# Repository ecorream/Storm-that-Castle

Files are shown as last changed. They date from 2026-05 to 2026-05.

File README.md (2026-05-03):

# Storm that Castle — Autonomous Multi-HILL Capture Robot

This repository documents the design, electronics, control logic, and competition outcome of **Team 6's autonomous robot** for the ME 588 STORM competition: **Storm that Castle: Fight to be King of the HILL**.

The robot was designed to autonomously navigate the playing field, detect HILL status using infrared frequency sensing, position itself using ultrasonic distance feedback, and deploy foam UNITs using a servo-based delivery system. The central strategy was to capture multiple HILLs at the end of the match by delivering several UNITs nearly simultaneously.

## Competition Result

The project was successful. Although the robot experienced some distance-sensing challenges during development and competition runs, the final system reached the final round of the competition. The robot tied in the final match and finished **second place only by tiebreaker**.

This result showed that the team's design approach, competition strategy, mechanical concept, electronics integration, and control implementation were sufficient to compete at a high level and validate the overall system architecture.

<p align="center">
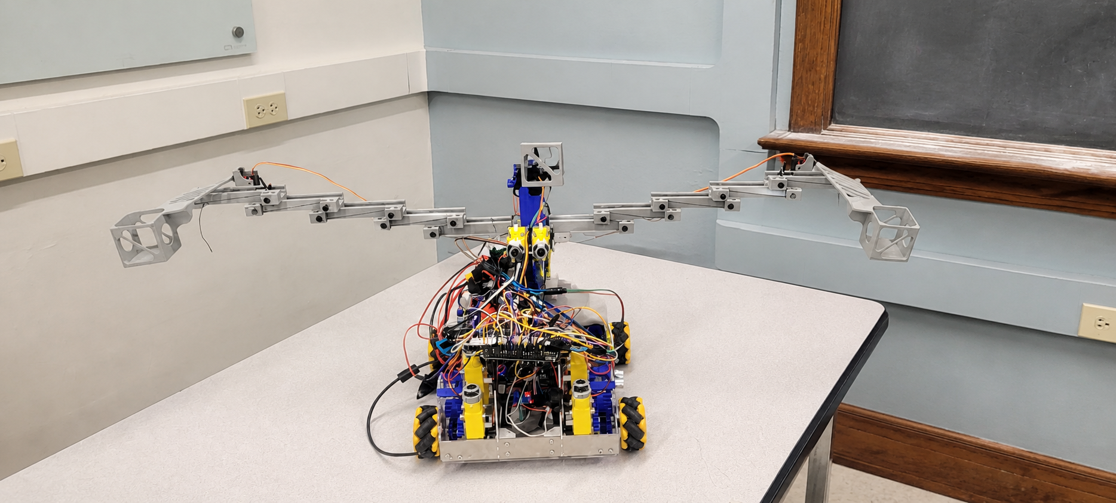
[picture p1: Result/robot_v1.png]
robot version 1
   
</p>

<p align="center">
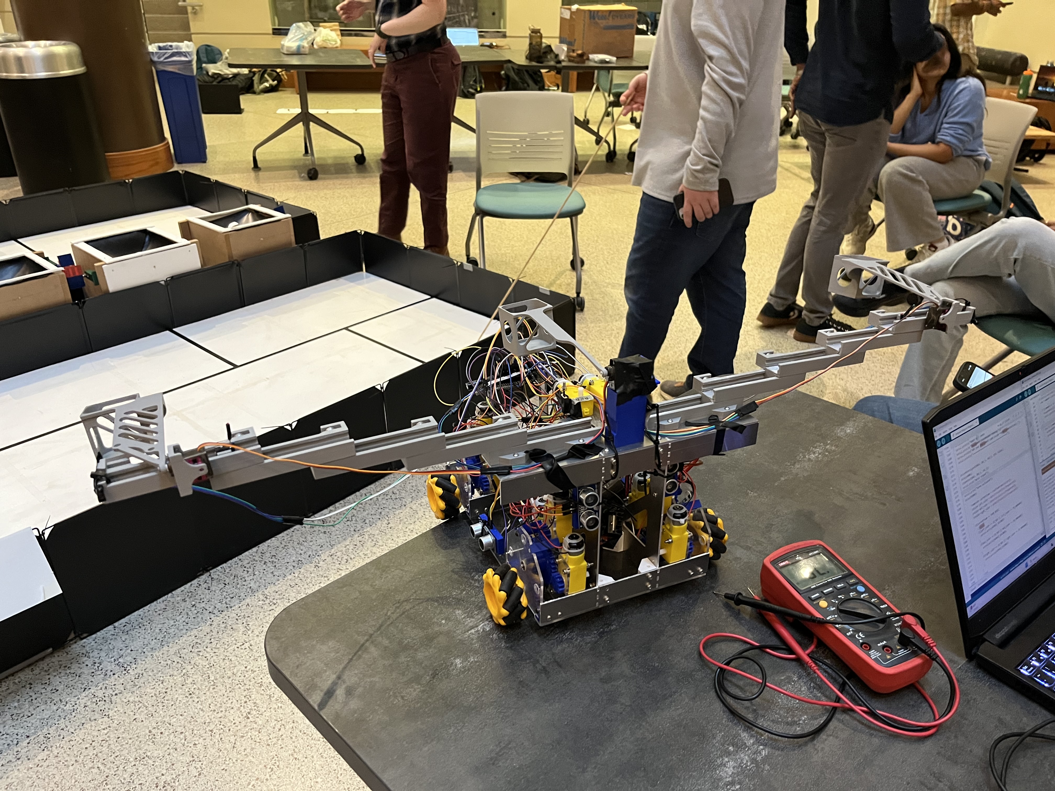
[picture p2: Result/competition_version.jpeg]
competition version robot
  
</p>

[Watch the final second round video](Result/final%20second%20round.mp4)

## Project Strategy

The main strategy was based on the fact that HILL control at the end of the match determines the result. Instead of continuously fighting for every HILL during the full match, the robot was designed to:

1. Navigate to the scoring position.
2. Align with multiple HILLs.
3. Deploy an extension/scoring system.
4. Release UNITs near the end of the match.
5. Capture multiple HILLs in a single final action.

This approach reduced the need for continuous scoring and focused on a decisive last-second capture.

## System Overview

The robot integrates the following major subsystems:

- **Mecanum-wheel drivetrain** for forward, backward, lateral, and alignment motion.
- **Ultrasonic sensing system** for distance-based navigation and positioning.
- **Infrared frequency detection system** for identifying HILL/team status.
- **AS5600 wheel encoders** connected through a TCA9548A I2C multiplexer.
- **Servo-controlled deployment system** for releasing UNITs.
- **APA102 LED display strip** for team selection and system status feedback.
- **Arduino Mega 2560** as the main controller.
- **L298N motor drivers** for drivetrain and deployment motor control.

## Repository Structure

```text
.
├── README.md
├── Competition_Arduino_code/
│   └── Competition_code.ino
├── Images/
│   ├── IR sensor.png
│   ├── arduino conections.png
│   ├── display.png
│   ├── encoders.png
│   ├── l298.png
│   ├── servos.png
│   ├── team selector.png
│   └── ultrasonic.png
├── KiCad files/
│   ├── lab7-backups/
│   ├── LEDS.kicad_sch
│   ├── distance.kicad_sch
│   ├── fp-info-cache
│   ├── lab7.kicad_pcb
│   ├── lab7.kicad_prl
│   ├── lab7.kicad_pro
│   ├── lab7.kicad_sch
│   ├── motors.kicad_sch
│   ├── power.kicad_sch
│   ├── servos.kicad_sch
│   └── untitled.kicad_sch
└── Result/
    ├── competition version.jpeg
    ├── drivetrain.png
    ├── final second round.mp4
    ├── robot.png
    └── robot_v1.jpeg
```

> The folder names above are recommended for organizing the GitHub repository. The images referenced in this README assume that all schematic images are stored inside the `Images/` folder.

## Electrical Architecture

The complete electrical system connects the Arduino Mega to the sensors, motor drivers, servos, LED strip, and team selector switch.

<p align="center">
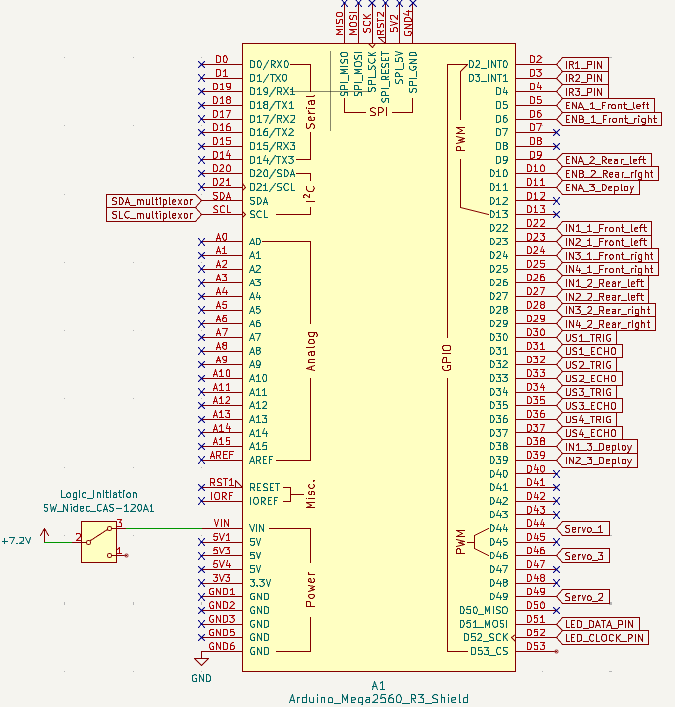
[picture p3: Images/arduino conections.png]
   
</p>

### Main Controller

The main controller is an **Arduino Mega 2560**, selected because the robot required a high number of digital I/O pins for ultrasonic sensors, IR sensors, motor drivers, servos, LEDs, and the I2C multiplexer.

## Team Selector

The team selector is implemented with a switch connected to the Arduino using an internal pull-up configuration. One side of the selector is connected to GND, and the signal pin is read by the controller to determine the active team color.

<p align="center">
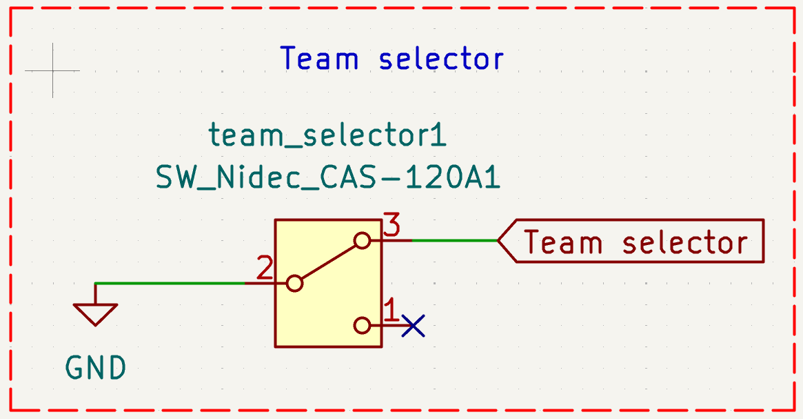
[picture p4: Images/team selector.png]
   
</p>

| Function | Arduino Pin | Notes |
|---|---:|---|
| Team selector signal | D40 | Uses `INPUT_PULLUP` |
| Switch common | GND | LOW state when connected to ground |

## Ultrasonic Sensor System

The robot uses four HC-SR04 ultrasonic sensors to estimate distances and support autonomous navigation. These sensors were used to approach HILL structures, maintain distance, and determine when the robot reached a deployment position.

<p align="center">
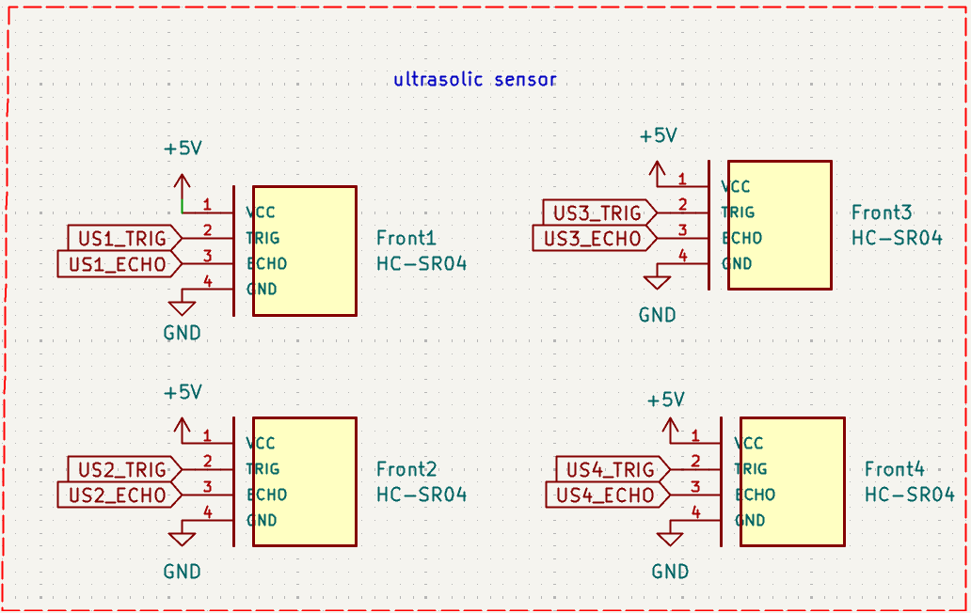
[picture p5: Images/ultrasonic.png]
   
</p>

| Sensor | Trigger Pin | Echo Pin | Purpose |
|---|---:|---:|---|
| US1 | D30 | D31 | Distance sensing |
| US2 | D32 | D33 | Distance sensing |
| US3 | D34 | D35 | Distance sensing |
| US4 | D36 | D37 | Distance sensing |

### Ultrasonic Calibration Notes

Some distance-sensing issues were observed during testing. The main improvements used during development were:

- Averaging multiple readings to reduce noise.
- Defining minimum and maximum valid distance thresholds.
- Using calibration offsets when two sensors were not mounted at exactly the same physical depth.
- Slowing the robot near the target to reduce overshoot.
- Testing distances repeatedly before competition runs.

Even with these challenges, the final robot was able to complete the strategy well enough to reach the final match.

## Infrared Frequency Sensor System

The IR system uses QSD123 NPN phototransistors with pull-up resistors. The Arduino reads the signal frequency and classifies the detected HILL/team state.

<p align="center">
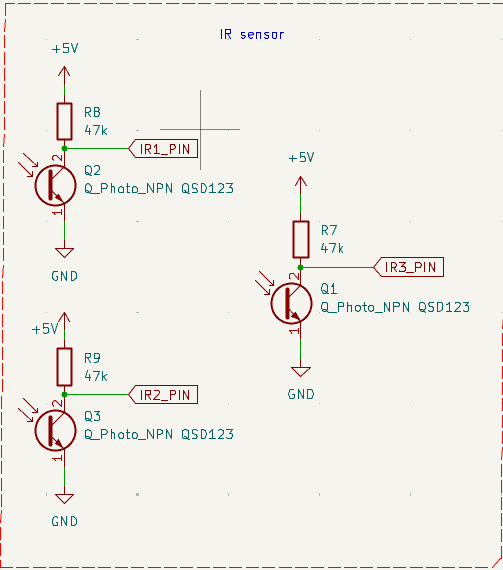
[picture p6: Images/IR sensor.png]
   
</p>

| IR Sensor | Arduino Pin | Function |
|---|---:|---|
| IR1 | D2 | Left reference / scoring position |
| IR2 | D3 | Center reference / scoring position |
| IR3 | D4 | Right reference / scoring position |

### Frequency Classification

The control software classifies the detected frequency into a team state. The working reference frequencies were:

| Team State | Approximate Frequency |
|---|---:|
| Blue | 780 Hz |
| Red | 1560 Hz |
| Unknown | Outside expected frequency range |

The IR readings were also displayed through the APA102 LED strip so the team could visually confirm what the robot was detecting during operation.

## Wheel Encoder System

Each wheel uses an AS5600 magnetic encoder. Because all AS5600 devices share the same I2C address, a **TCA9548A I2C multiplexer** is used to isolate each encoder on a separate bus channel.

<p align="center">
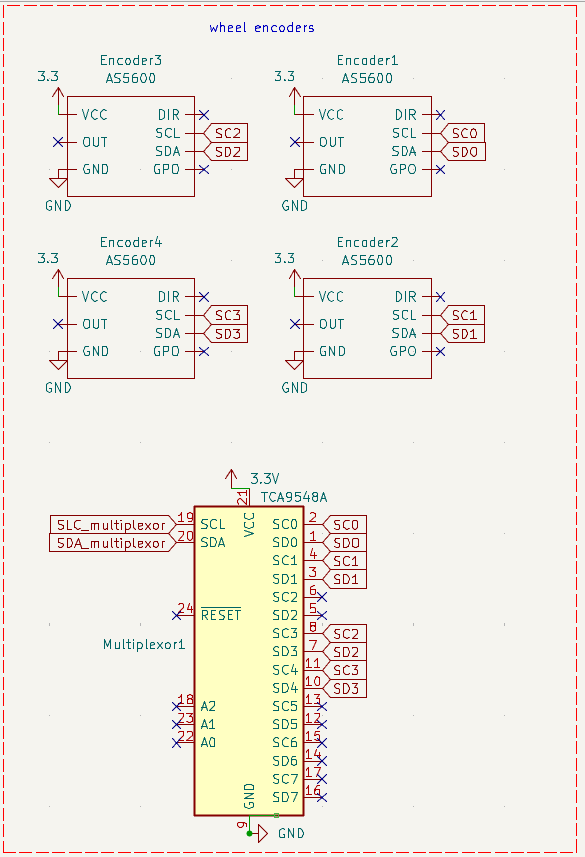
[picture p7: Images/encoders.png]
   
</p>

| Encoder | MUX Channel | Wheel Location |
|---|---:|---|
| Encoder 1 | Channel 0 | Front / drivetrain feedback |
| Encoder 2 | Channel 1 | Rear / drivetrain feedback |
| Encoder 3 | Channel 3 | Front / drivetrain feedback |
| Encoder 4 | Channel 4 | Rear / drivetrain feedback |

| I2C Signal | Arduino Mega Pin |
|---|---:|
| SDA | D20 |
| SCL | D21 |

The encoders were used mainly for wheel feedback, debugging, motor direction verification, and improving motion consistency.

## LED Display System

The robot uses an APA102 LED strip to provide visual feedback for team selection, navigation state, point detection, and IR frequency classification.

<p align="center">
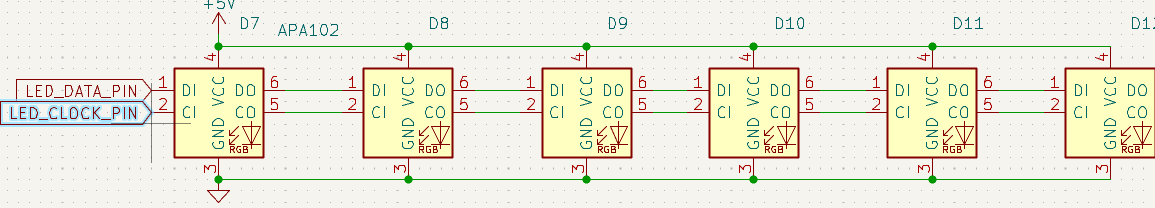
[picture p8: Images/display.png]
   
</p>

| LED Signal | Arduino Pin |
|---|---:|
| LED data | D51 |
| LED clock | D52 |
| VCC | +5V |
| GND | GND |

### LED Status Concept

| LED Position | Status Role |
|---|---|
| LED 1 | Selected team color |
| LED 2 | General system status |
| LED 3 | Navigation / deployment point status |
| LED 4 | IR1 detected team/frequency |
| LED 5 | IR2 detected team/frequency |
| LED 6 | IR3 detected team/frequency |

Example status logic:

- **Blue or Red**: selected team or detected HILL state.
- **Green**: robot reached the deployment point.
- **Orange**: ready or waiting state.
- **Off**: inactive or unknown state.

## Servo Deployment System

The deployment system uses three SG90 servos to release UNITs from individual scoop mechanisms. This approach was selected instead of a launcher because it was mechanically simpler, more repeatable, and easier to control.

<p align="center">
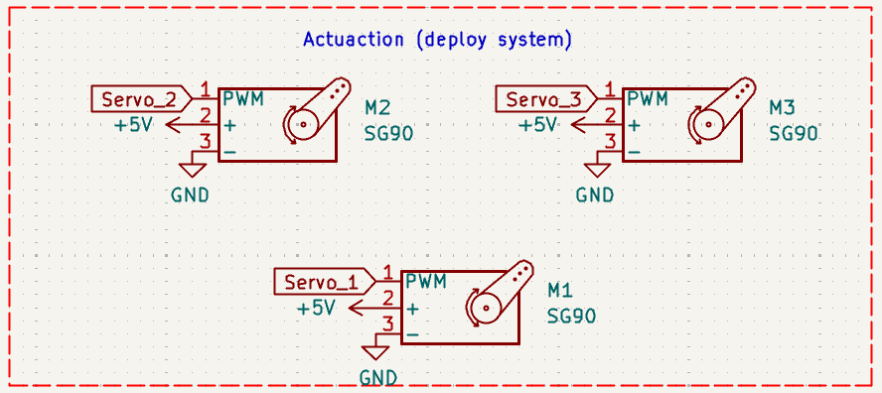
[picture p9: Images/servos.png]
   
</p>

| Servo | Arduino Pin | Function |
|---|---:|---|
| Servo 1 | D44 | Left/primary scoop mechanism |
| Servo 2 | D49 | Center scoop mechanism |
| Servo 3 | D46 | Right scoop mechanism |

> Note: If the firmware version uses Servo 2 on D45, keep the schematic and code synchronized before uploading.

### Servo Motion Concept

The deployment sequence uses two main positions:

```cpp
// Holding / initial position
servo1.write(0);
servo2.write(180);
servo3.write(180);

// Deployment position
servo1.write(180);
servo2.write(0);
servo3.write(0);
```

A short delay was added between commands to avoid sudden motion and reduce mechanical stress on the scoop connections.

## Motor Driver and Motion System

The drivetrain and deployment motor are controlled using L298N motor drivers. The mecanum-wheel configuration allows the robot to move forward, backward, sideways, and make fine alignment corrections.

<p align="center">
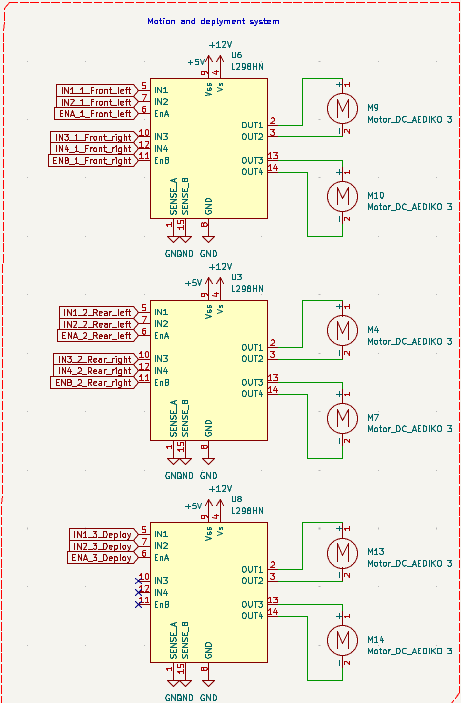
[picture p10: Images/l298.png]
   
</p>

### Motor Driver Pin Map

| Subsystem | Arduino Pin | Function |
|---|---:|---|
| Front left ENA | D5 | PWM speed control |
| Front left IN1 | D22 | Direction control |
| Front left IN2 | D23 | Direction control |
| Front right ENB | D6 | PWM speed control |
| Front right IN3 | D24 | Direction control |
| Front right IN4 | D25 | Direction control |
| Rear left ENA | D9 | PWM speed control |
| Rear left IN1 | D26 | Direction control |
| Rear left IN2 | D27 | Direction control |
| Rear right ENB | D10 | PWM speed control |
| Rear right IN3 | D28 | Direction control |
| Rear right IN4 | D29 | Direction control |
| Deploy motor ENA | D11 | PWM speed control |
| Deploy motor IN1 | D38 | Direction control |
| Deploy motor IN2 | D39 | Direction control |

## Control Strategy

The robot behavior was organized using a finite-state-machine style control approach. This made the autonomous routine easier to test, debug, and modify.

### Main States

| State | Description |
|---|---|
| Idle | Wait for start condition |
| Team Selection | Read selected team color |
| Navigate | Move toward the target region |
| Lateral Alignment | Move sideways using mecanum wheels |
| IR Detection | Detect HILL/team state through IR frequency |
| Approach | Move to the required ultrasonic distance |
| Deploy | Extend mechanism and release UNITs |
| Stop / Finish | End the autonomous routine |

### General Autonomous Flow

```text
Start
  ↓
Read team selector
  ↓
Begin navigation
  ↓
Use ultrasonic sensors for distance feedback
  ↓
Move laterally to the target HILL region
  ↓
Approach final deployment distance
  ↓
Deploy mechanism
  ↓
Detect IR references and HILL/team state
  ↓
Release UNITs with servos
  ↓
Stop
```

## Mechanical Design Summary

The robot used a compact frame with a mecanum-wheel drivetrain and a deployable scoring mechanism. Instead of storing and launching many UNITs from a single mechanism, the design used individual scoops that held one UNIT each. This reduced complexity and improved control over the release event.

Key mechanical features:

- Compact robot structure to satisfy competition size constraints.
- Mecanum wheels for lateral movement and alignment.
- Servo-driven scoop mechanisms for controlled UNIT release.
- Extension/deployment mechanism to reach multiple HILLs.
- Modular structure for easier testing and repair.

## Testing and Iteration

The robot was tested through multiple subsystem and full-system trials. Important testing activities included:

- Individual motor direction testing.
- Mecanum movement testing.
- Ultrasonic distance calibration.
- IR frequency classification tests.
- Encoder channel validation through the multiplexer.
- Servo deployment timing tests.
- Full autonomous routine testing.

<p align="center">
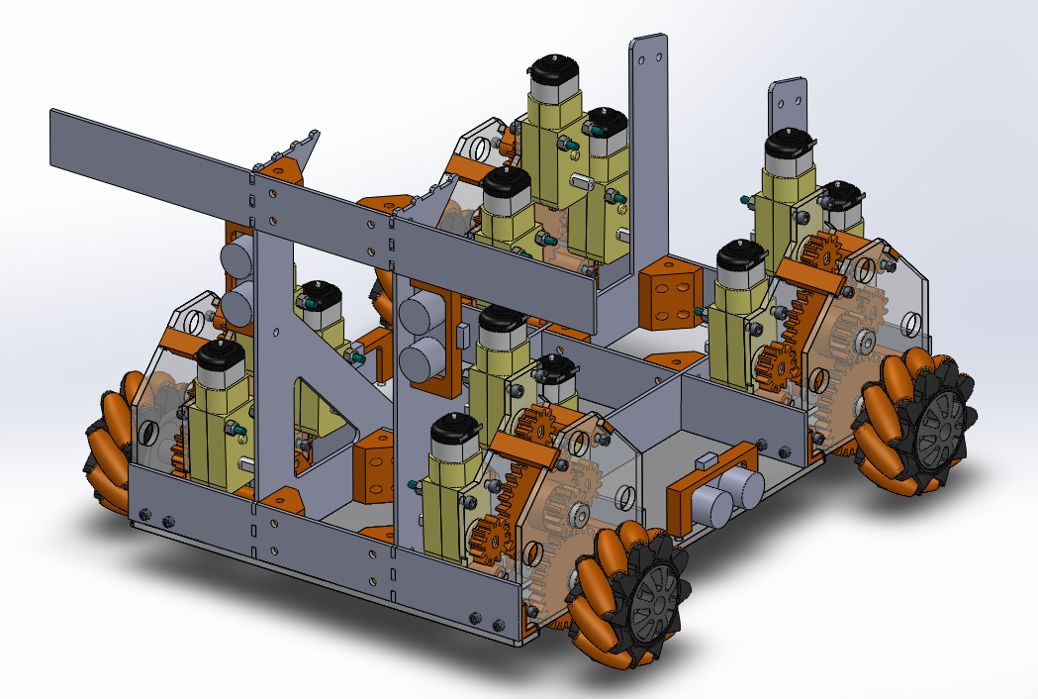
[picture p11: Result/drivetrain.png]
drivetrain chassis
  
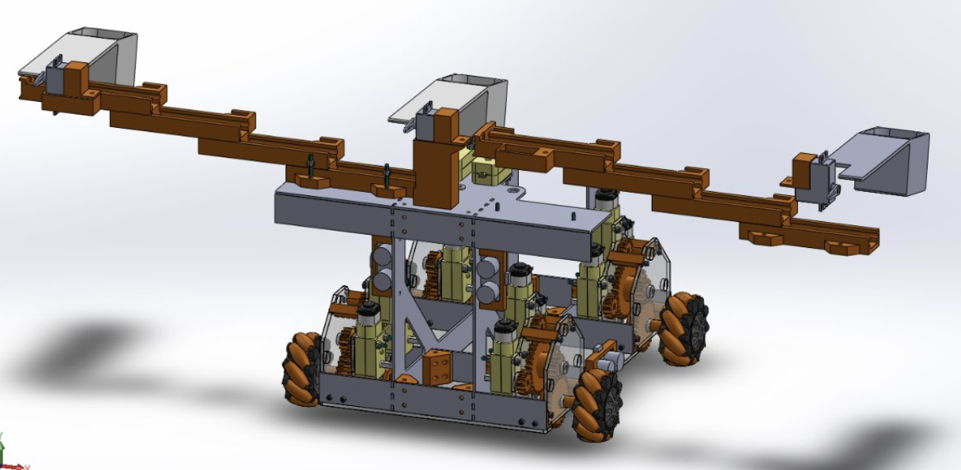
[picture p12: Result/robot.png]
final robot
  
</p>

The most important improvements came from sensor calibration, motor speed tuning, and adjusting the timing between navigation, alignment, deployment, and servo release.

## Known Challenges

The main challenges during the project were:

- Ultrasonic distance readings varied depending on angle, surface, and robot alignment.
- Sensor placement differences required calibration offsets.
- Mecanum movement required careful motor direction and speed tuning.
- Servo movement needed timing delays to avoid mechanical strain.
- IR frequency detection required threshold tuning to avoid unknown readings.

Despite these limitations, the final robot performed competitively and reached the final match.

## Final Outcome

The robot achieved the main project goals:

- Autonomous navigation was implemented.
- HILL detection and positioning were achieved using ultrasonic sensing.
- IR frequency detection was integrated into the system.
- UNIT delivery was completed with a servo-based deployment mechanism.
- The team reached the competition final.
- The final match ended in a tie, and the robot finished second only due to the tiebreaker.

This confirmed that the project strategy, system integration, and design decisions were successful.

## Team

**Team 6**

- Aadit Kumar
- Arijeet Kamat
- Dhanush Manjunath
- Emmanuel Correa Morales
- Kyle DeLay
- Supreet Mishra

## Acknowledgments

This project was completed for ME 588 as part of the STORM autonomous robot competition. The team acknowledges the support of the course staff, lab resources, machine shop access, and testing opportunities that made the final robot possible.

## Future Improvements

Possible improvements for a future version include:

- More robust distance estimation using sensor fusion.
- Improved ultrasonic mounting to reduce angle-related errors.
- Closed-loop mecanum control using encoder feedback.
- Better mechanical isolation for servo loads.
- More compact PCB integration.
- Additional validation routines before autonomous start.

## License
This repository is intended for academic documentation and educational use. Add a specific license file if the project will be shared publicly or reused by other teams.

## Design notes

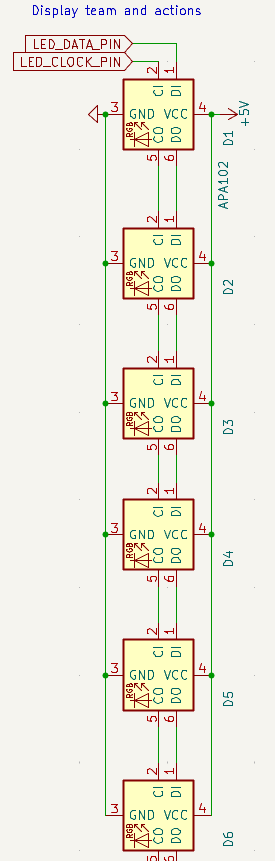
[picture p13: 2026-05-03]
Schamatic images/display.png

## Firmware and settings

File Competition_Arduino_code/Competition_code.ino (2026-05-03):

// libraries needed 
#include <Wire.h>
#include <FastLED.h>
#include <math.h>
#include <string.h>
#include <Servo.h>
//  SELECTOR
// Pin 40 with INPUT_PULLUP:
// Low = RED
// High =  BLUE

#define SELECTOR_PIN 40

enum TeamColor {
  TEAM_RED,
  TEAM_BLUE
};

TeamColor activeTeam = TEAM_BLUE;


// APA102 code information//
// LED 1 Selected team color
// LED 2 General system status
// LED 3  Navigation point status:
//         BLUE  = robot is navigating
//          GREEN = robot reached deployment point
//
// LED 4 IR1 detected color/ frequency display
// LED 5 IR2 detected color/ frequency display
// LED 6 IR3 detected color /frequency display

#define NUM_LEDS   6
#define DATA_PIN   51
#define CLOCK_PIN  52
#define BRIGHTNESS 50

CRGB leds[NUM_LEDS];

const uint8_t LED1_TEAM    = 0;
const uint8_t LED2_STATUS  = 1;
const uint8_t LED3_MOTION  = 2;
const uint8_t LED4_IR1     = 3;
const uint8_t LED5_IR2     = 4;
const uint8_t LED6_IR3     = 5;

// IR frecuendy sensors
// IR1  Pin 2 Left reference
// IR2  Pin 3 Center reference
// IR3 Pin 4  Right reference

#define ENABLE_IR_DISPLAY true

#define IR1_PIN 2
#define IR2_PIN 3
#define IR3_PIN 4

// this frecuencies have a upper band and a higer band
#define RED_MIN   1250.0
#define RED_MAX   1600.0

#define BLUE_MIN  700.0
#define BLUE_MAX  900.0

// Short timeout so navigation does not freeze if there is no IR signal
// 3000 us is enough for the expected 780 Hz and 1560 Hz signals
#define IR_PULSE_TIMEOUT_US 3000UL

const unsigned long IR_UPDATE_INTERVAL_MS = 200;
unsigned long lastIrUpdateTime = 0;

enum IrColor {
  IR_UNKNOWN,
  IR_RED,
  IR_BLUE
};

struct IrReading {
  float frequencyHz;
  IrColor color;
};

IrReading ir1 = {0.0, IR_UNKNOWN};
IrReading ir2 = {0.0, IR_UNKNOWN};
IrReading ir3 = {0.0, IR_UNKNOWN};

// ULTRASONIC SENSORS
// US1  left
// US2  front left
// US3  front right
// US4  right
#define US1_TRIG 30
#define US1_ECHO 31
#define US2_TRIG 32
#define US2_ECHO 33
#define US3_TRIG 34
#define US3_ECHO 35
#define US4_TRIG 36
#define US4_ECHO 37

const unsigned long ULTRASONIC_TIMEOUT_US = 12000;  // about 200 cm max range
const unsigned long SENSOR_UPDATE_INTERVAL_MS = 80;
unsigned long lastSensorUpdateTime = 0;

struct UltrasonicReading {
  float cm;
  float lastGoodCm;
  bool valid;
  bool hasLastGood;
};

UltrasonicReading us1Left   = {0, 0, false, false};
UltrasonicReading us2FrontL = {0, 0, false, false};
UltrasonicReading us3FrontR = {0, 0, false, false};
UltrasonicReading us4Right  = {0, 0, false, false};


// NAVIGATION 
//
// Sequence:
// 1) Move forward following the side wall until front distance <= FRONT_TRIGGER_CM.
// 2) Move laterally to the selected side point.
//          RED  lateral left, using US4 right sensor until RED_SIDE_ARRIVAL_CM.
//          BLUE lateral right, using US1 left sensor until BLUE_SIDE_ARRIVAL_CM.
// 3) After reaching the lateral point, move forward until DEPLOY_FRONT_CM.
// 4) Stop at deployment point. LED3 becomes GREEN.
// 
const unsigned long TOTAL_RUN_TIME_MS = 144000UL;  // 2 min and 30 s
const unsigned long LAST_ALERT_MS     = 30000UL;   //last 30 s

const float ROBOT_WIDTH_CM = 23.0;

float WALL_TARGET_CM        = 15.0;
float FRONT_TRIGGER_CM      = 20.0;
float RED_SIDE_ARRIVAL_CM   = 122.0;
float BLUE_SIDE_ARRIVAL_CM  = 83.0;
float DEPLOY_FRONT_CM       = 6.0;


// FRONT ULTRASONIC CALIBRATION
// I measured this for physical differences in the robot:
float US2_FRONT_OFFSET_CM = 0.0;
float US3_FRONT_OFFSET_CM = 1.16;

float FRONT_SAFETY_CM = 8.0;
float SIDE_SAFETY_CM  = 8.0;

float NAV_SPEED_DPS      = 560.0;
float LATERAL_SPEED_DPS  = 540.0;
float APPROACH_SPEED_DPS = 420.0;

float KP_SIDE_WALL  = 0.045;
float KP_FRONT_HOLD = 0.040;
float KP_FRONT_APP  = 0.070;

float lateralFrontReferenceCm = FRONT_TRIGGER_CM;

unsigned long robotStartTime = 0;
unsigned long stateStartTime = 0;

//SERVOS
Servo servo1;
Servo servo2;
Servo servo3;
#define SERVO1_PIN 44
#define SERVO2_PIN 49
#define SERVO3_PIN 46

//initial servo positions
const int SERVO1_INITIAL = 0;
const int SERVO2_INITIAL = 150;
const int SERVO3_INITIAL = 180;

//deployment servo positions
const int SERVO1_SECOND = 180;
const int SERVO2_SECOND = 0;
const int SERVO3_SECOND = 0;

bool servosAttached = false;


// I2C addresses miltiplexors
#define TCA_ADDR    0x70
#define AS5600_ADDR 0x36
#define AS5600_RAW_ANGLE_H 0x0C


//Multiplexer channels
//D0 Front Left
//D1 Rear Left
//D3 Rear Right
//D4 Front Right

#define ENC_FRONT_LEFT   0
#define ENC_REAR_LEFT    1
#define ENC_REAR_RIGHT   3
#define ENC_FRONT_RIGHT  4

//L298 #1
//Motor A -> Front Left
//Motor B -> Front Right
#define ENA1 5
#define IN1_1 22
#define IN2_1 23
#define IN3_1 24
#define IN4_1 25
#define ENB1 6

//L298 #2
//Motor A  Rear Left
//Motor B Rear Right
#define ENA2 9
#define IN1_2 26
#define IN2_2 27
#define IN3_2 28
#define IN4_2 29
#define ENB2 10

//Deployment mechanism

#define ENA3 11
#define IN1_3 38
#define IN2_3 39

// Wheel indexes
#define IDX_FL 0
#define IDX_FR 1
#define IDX_RL 2
#define IDX_RR 3

// Direction correction
// Positive command means physical forward

bool FRONT_LEFT_REVERSED  = true;
bool FRONT_RIGHT_REVERSED = true;
bool REAR_LEFT_REVERSED   = true;
bool REAR_RIGHT_REVERSED  = true;

// Encoder-based speed control settings
float minTargetDps = 80.0;
float maxTargetDps = 1200.0;

float KP_SPEED = 0.12;
float KI_SPEED = 0.03;

int MIN_PWM = 70;
int MAX_PWM = 255;

bool STOP_MOTOR_IF_ENCODER_FAILS = true;

const unsigned long CONTROL_INTERVAL_MS = 50;
const unsigned long PRINT_INTERVAL_MS   = 500;

unsigned long lastControlTime = 0;
unsigned long lastPrintTime   = 0;

// this measure can be change, this is going to affect navigation
float WHEEL_DIAMETER_CM = 6.5;

struct WheelController {
  const char* name;
  int enPin;
  int in1Pin;
  int in2Pin;
  uint8_t encChannel;
  bool reversed;

  int commandSign;
  float targetDps;
  float measuredSignedDps;
  float measuredAbsDps;
  float filteredDps;
  float integral;
  float pwm;

  uint16_t rawAngle;
  float angleDeg;
  uint16_t previousRaw;
  bool hasPrevious;
  bool encoderOk;

  float totalDeg;
};

WheelController wheels[4] = {
  {"FL", ENA1, IN1_1, IN2_1, ENC_FRONT_LEFT,  true, 0, 0, 0, 0, 0, 0, 0, 0, 0, 0, false, false, 0},
  {"FR", ENB1, IN3_1, IN4_1, ENC_FRONT_RIGHT, true, 0, 0, 0, 0, 0, 0, 0, 0, 0, 0, false, false, 0},
  {"RL", ENA2, IN1_2, IN2_2, ENC_REAR_LEFT,   true, 0, 0, 0, 0, 0, 0, 0, 0, 0, 0, false, false, 0},
  {"RR", ENB2, IN3_2, IN4_2, ENC_REAR_RIGHT,  true, 0, 0, 0, 0, 0, 0, 0, 0, 0, 0, false, false, 0}
};

const char* currentMovementName = "STOP";

// NAVIGATION STATE MACHINE
enum NavigationState {
  STATE_FORWARD_WALL_FOLLOW,
  STATE_LATERAL_SEARCH,
  STATE_APPROACH_DEPLOY,
  STATE_DEPLOY_WAIT,
  STATE_FINISHED,
  STATE_EMERGENCY_STOP
};

NavigationState navState = STATE_FORWARD_WALL_FOLLOW;

// This flag prevents the deployment code from running many times
bool deploymentActionDone = false;

// Basic Funtions helpers
float clampFloat(float value, float low, float high) {
  if (value < low) return low;
  if (value > high) return high;
  return value;
}

TeamColor readTeamFromSelector() {
  int estadoSelector = digitalRead(SELECTOR_PIN);

  if (estadoSelector == LOW) {
    return TEAM_RED;
  } else {
    return TEAM_BLUE;
  }
}

const char* teamName(TeamColor team) {
  if (team == TEAM_RED) return "ROJO";
  return "AZUL";
}

CRGB teamLedColor(TeamColor team) {
  if (team == TEAM_RED) return CRGB::Red;
  return CRGB::Blue;
}

// please be carefull this has to be activated before star the arduino
// once we start we can't change the actions
void printTeamSelector() {
  int estadoSelector = digitalRead(SELECTOR_PIN);

  Serial.print("Pin 40: ");

  if (estadoSelector == LOW) {
    Serial.println("LOW -> ROJO");
  } else {
    Serial.println("HIGH -> AZUL");
  }
}

// states
const char* stateName(NavigationState state) {
  switch (state) {
    case STATE_FORWARD_WALL_FOLLOW: return "FORWARD_WALL_FOLLOW";
    case STATE_LATERAL_SEARCH:      return "LATERAL_SEARCH";
    case STATE_APPROACH_DEPLOY:     return "APPROACH_DEPLOY";
    case STATE_DEPLOY_WAIT:         return "DEPLOY_WAIT";
    case STATE_FINISHED:            return "FINISHED";
    case STATE_EMERGENCY_STOP:      return "EMERGENCY_STOP";
    default:                        return "UNKNOWN";
  }
}

void enterState(NavigationState newState) {
  navState = newState;
  stateStartTime = millis();

  if (navState == STATE_DEPLOY_WAIT) {
    deploymentActionDone = false;
  }

  Serial.println();
  Serial.print("New navigation state: ");
  Serial.println(stateName(navState));
}

// I2C for encoders AS5600 functions multiplexor will manage the address
bool i2cDeviceFound(uint8_t address) {
  Wire.beginTransmission(address);
  byte error = Wire.endTransmission();
  return error == 0;
}

bool selectMuxChannel(uint8_t channel) {
  if (channel > 7) return false;
  Wire.beginTransmission(TCA_ADDR);
  Wire.write(1 << channel);
  byte error = Wire.endTransmission();
  return error == 0;
}

bool readAS5600RawAngle(uint8_t muxChannel, uint16_t &rawAngle) {
  if (!selectMuxChannel(muxChannel)) return false;

  Wire.beginTransmission(AS5600_ADDR);
  Wire.write(AS5600_RAW_ANGLE_H);

  if (Wire.endTransmission(false) != 0) return false;

  Wire.requestFrom(AS5600_ADDR, (uint8_t)2);

  if (Wire.available() < 2) return false;

  uint8_t highByte = Wire.read();
  uint8_t lowByte  = Wire.read();

  rawAngle = ((highByte & 0x0F) << 8) | lowByte;

  return true;
}

float rawToDegrees(uint16_t rawAngle) {
  return rawAngle * 360.0 / 4096.0;
}

float angleDifference(float currentDeg, float previousDeg) {
  float diff = currentDeg - previousDeg;
  if (diff > 180.0) diff -= 360.0;
  if (diff < -180.0) diff += 360.0;
  return diff;
}


// Motor functions
void driveMotorSigned(int enPin, int in1Pin, int in2Pin, int signedPwm, bool reversed) {
  signedPwm = constrain(signedPwm, -255, 255);

  if (reversed) {
    signedPwm = -signedPwm;
  }
  int pwmValue = abs(signedPwm);
  if (signedPwm > 0) {
    digitalWrite(in1Pin, HIGH);
    digitalWrite(in2Pin, LOW);
  } else if (signedPwm < 0) {
    digitalWrite(in1Pin, LOW);
    digitalWrite(in2Pin, HIGH);
  } else {
    digitalWrite(in1Pin, LOW);
    digitalWrite(in2Pin, LOW);
  }
  analogWrite(enPin, pwmValue);
}

void stopMotor(int enPin, int in1Pin, int in2Pin) {
  digitalWrite(in1Pin, LOW);
  digitalWrite(in2Pin, LOW);
  analogWrite(enPin, 0);
}

void stopAllMotors() {
  stopMotor(ENA1, IN1_1, IN2_1);
  stopMotor(ENB1, IN3_1, IN4_1);
  stopMotor(ENA2, IN1_2, IN2_2);
  stopMotor(ENB2, IN3_2, IN4_2);

  
  stopMotor(ENA3, IN1_3, IN2_3);

  for (int i = 0; i < 4; i++) {
    wheels[i].commandSign = 0;
    wheels[i].targetDps = 0;
    wheels[i].integral = 0;
    wheels[i].pwm = 0;
  }
  currentMovementName = "STOP";
}

void setWheelTarget(int index, float component, float baseSpeedDps) {
  float absComponent = fabs(component);

  if (absComponent < 0.05) {
    wheels[index].commandSign = 0;
    wheels[index].targetDps = 0;
    wheels[index].integral = 0;
    wheels[index].pwm = 0;
    return;
  }

  wheels[index].commandSign = component > 0 ? +1 : -1;
  wheels[index].targetDps = clampFloat(baseSpeedDps * absComponent, minTargetDps, maxTargetDps);
}

// x: +right, -left
// y: +forward, -backward
// rot: +rotate right, -rotate left
void setMecanumVector(float x, float y, float rot, float baseSpeedDps, const char* movementName) {
  float fl = y + x + rot;
  float fr = y - x - rot;
  float rl = y - x + rot;
  float rr = y + x - rot;

  float maxAbs = fabs(fl);

  if (fabs(fr) > maxAbs) maxAbs = fabs(fr);
  if (fabs(rl) > maxAbs) maxAbs = fabs(rl);
  if (fabs(rr) > maxAbs) maxAbs = fabs(rr);

  if (maxAbs > 1.0) {
    fl /= maxAbs;
    fr /= maxAbs;
    rl /= maxAbs;
    rr /= maxAbs;
  }

  setWheelTarget(IDX_FL, fl, baseSpeedDps);
  setWheelTarget(IDX_FR, fr, baseSpeedDps);
  setWheelTarget(IDX_RL, rl, baseSpeedDps);
  setWheelTarget(IDX_RR, rr, baseSpeedDps);

  currentMovementName = movementName;
}


// Encoder update and PI speed control
void updateWheelMeasurement(WheelController &wheel, float dtSec) {
  uint16_t currentRaw;

  if (!readAS5600RawAngle(wheel.encChannel, currentRaw)) {
    wheel.encoderOk = false;
    wheel.rawAngle = 0;
    wheel.angleDeg = 0;
    wheel.measuredSignedDps = 0;
    wheel.measuredAbsDps = 0;
    wheel.filteredDps = 0;
    return;
  }

  wheel.encoderOk = true;
  wheel.rawAngle = currentRaw;
  wheel.angleDeg = rawToDegrees(currentRaw);

  if (!wheel.hasPrevious) {
    wheel.previousRaw = currentRaw;
    wheel.hasPrevious = true;
    wheel.measuredSignedDps = 0;
    wheel.measuredAbsDps = 0;
    wheel.filteredDps = 0;
    return;
  }

  float currentDeg = rawToDegrees(currentRaw);
  float previousDeg = rawToDegrees(wheel.previousRaw);
  float diffDeg = angleDifference(currentDeg, previousDeg);

  wheel.measuredSignedDps = diffDeg / dtSec;
  wheel.measuredAbsDps = fabs(wheel.measuredSignedDps);
  wheel.filteredDps = 0.70 * wheel.filteredDps + 0.30 * wheel.measuredAbsDps;
  wheel.totalDeg += diffDeg;

  wheel.previousRaw = currentRaw;
}

void updateWheelControl(WheelController &wheel, float dtSec) {
  if (wheel.commandSign == 0 || wheel.targetDps <= 0) {
    wheel.integral = 0;
    wheel.pwm = 0;
    driveMotorSigned(wheel.enPin, wheel.in1Pin, wheel.in2Pin, 0, wheel.reversed);
    return;
  }

  if (!wheel.encoderOk && STOP_MOTOR_IF_ENCODER_FAILS) {
    wheel.integral = 0;
    wheel.pwm = 0;
    driveMotorSigned(wheel.enPin, wheel.in1Pin, wheel.in2Pin, 0, wheel.reversed);
    return;
  }

  float basePwm = wheel.targetDps * 0.32;
  basePwm = clampFloat(basePwm, MIN_PWM, MAX_PWM);
  float error = wheel.targetDps - wheel.filteredDps;
  wheel.integral += error * dtSec;
  wheel.integral = clampFloat(wheel.integral, -600.0, 600.0);
  float outputPwm = basePwm + KP_SPEED * error + KI_SPEED * wheel.integral;
  outputPwm = clampFloat(outputPwm, MIN_PWM, MAX_PWM);

  wheel.pwm = outputPwm;

  int signedPwm = wheel.commandSign * (int)wheel.pwm;

  driveMotorSigned(wheel.enPin, wheel.in1Pin, wheel.in2Pin, signedPwm, wheel.reversed);
}

void updateAllWheelControllers() {
  unsigned long now = millis();
  if (now - lastControlTime < CONTROL_INTERVAL_MS) return;
  float dtSec = (now - lastControlTime) / 1000.0;
  lastControlTime = now;

  if (dtSec <= 0) return;

  for (int i = 0; i < 4; i++) {
    updateWheelMeasurement(wheels[i], dtSec);
  }

  for (int i = 0; i < 4; i++) {
    updateWheelControl(wheels[i], dtSec);
  }
}

// Ultrasonic 

void setupUltrasonicPins() {
  pinMode(US1_TRIG, OUTPUT);
  pinMode(US1_ECHO, INPUT);

  pinMode(US2_TRIG, OUTPUT);
  pinMode(US2_ECHO, INPUT);

  pinMode(US3_TRIG, OUTPUT);
  pinMode(US3_ECHO, INPUT);

  pinMode(US4_TRIG, OUTPUT);
  pinMode(US4_ECHO, INPUT);

  digitalWrite(US1_TRIG, LOW);
  digitalWrite(US2_TRIG, LOW);
  digitalWrite(US3_TRIG, LOW);
  digitalWrite(US4_TRIG, LOW);
}

float readUltrasonicCm(int trigPin, int echoPin) {
  digitalWrite(trigPin, LOW);
  delayMicroseconds(2);

  digitalWrite(trigPin, HIGH);
  delayMicroseconds(10);

  digitalWrite(trigPin, LOW);

  unsigned long duration = pulseIn(echoPin, HIGH, ULTRASONIC_TIMEOUT_US);

  if (duration == 0) {
    return -1.0;
  }

  float cm = duration * 0.0343 / 2.0;

  if (cm < 2.0 || cm > 200.0) {
    return -1.0;
  }

  return cm;
}

void updateOneUltrasonic(UltrasonicReading &reading, int trigPin, int echoPin) {
  float value = readUltrasonicCm(trigPin, echoPin);

  if (value > 0) {
    reading.cm = value;
    reading.lastGoodCm = value;
    reading.valid = true;
    reading.hasLastGood = true;
  } else {
    reading.valid = false;

    if (reading.hasLastGood) {
      reading.cm = reading.lastGoodCm;
    } else {
      reading.cm = -1.0;
    }
  }
}

void updateUltrasonicSensors() {
  unsigned long now = millis();

  if (now - lastSensorUpdateTime < SENSOR_UPDATE_INTERVAL_MS) return;

  lastSensorUpdateTime = now;

  updateOneUltrasonic(us1Left, US1_TRIG, US1_ECHO);
  delayMicroseconds(500);
  updateOneUltrasonic(us2FrontL, US2_TRIG, US2_ECHO);
  delayMicroseconds(500);
  updateOneUltrasonic(us3FrontR, US3_TRIG, US3_ECHO);
  delayMicroseconds(500);

  updateOneUltrasonic(us4Right, US4_TRIG, US4_ECHO);
}

float correctedUS2FrontCm() {
  return us2FrontL.cm + US2_FRONT_OFFSET_CM;
}

float correctedUS3FrontCm() {
  return us3FrontR.cm + US3_FRONT_OFFSET_CM;
}

float correctedUS2FrontLastGoodCm() {
  return us2FrontL.lastGoodCm + US2_FRONT_OFFSET_CM;
}

float correctedUS3FrontLastGoodCm() {
  return us3FrontR.lastGoodCm + US3_FRONT_OFFSET_CM;
}

bool getFrontAverage(float &avgCm, bool requireFreshReading) {
  float sum = 0;
  int count = 0;

  if (us2FrontL.valid) {
    sum += correctedUS2FrontCm();
    count++;
  }

  if (us3FrontR.valid) {
    sum += correctedUS3FrontCm();
    count++;
  }

  if (count > 0) {
    avgCm = sum / count;
    return true;
  }

  if (!requireFreshReading) {
    if (us2FrontL.hasLastGood && us3FrontR.hasLastGood) {
      avgCm = (correctedUS2FrontLastGoodCm() + correctedUS3FrontLastGoodCm()) / 2.0;
      return true;
    }

    if (us2FrontL.hasLastGood) {
      avgCm = correctedUS2FrontLastGoodCm();
      return true;
    }

    if (us3FrontR.hasLastGood) {
      avgCm = correctedUS3FrontLastGoodCm();
      return true;
    }
  }

  avgCm = -1.0;
  return false;
}

bool getSideDistanceForTeam(TeamColor team, float &sideCm) {
  if (team == TEAM_RED) {
    if (us4Right.valid) {
      sideCm = us4Right.cm;
      return true;
    }

    if (us4Right.hasLastGood) {
      sideCm = us4Right.lastGoodCm;
      return true;
    }
  } else {
    if (us1Left.valid) {
      sideCm = us1Left.cm;
      return true;
    }

    if (us1Left.hasLastGood) {
      sideCm = us1Left.lastGoodCm;
      return true;
    }
  }

  sideCm = -1.0;
  return false;
}

// IR FREQUENCY fucntions
float readFrequency(int pin) {
  unsigned long highTime = pulseIn(pin, HIGH, IR_PULSE_TIMEOUT_US);
  unsigned long lowTime  = pulseIn(pin, LOW, IR_PULSE_TIMEOUT_US);

  if (highTime == 0 || lowTime == 0) {
    return 0.0;
  }

  unsigned long period = highTime + lowTime;

  if (period == 0) {
    return 0.0;
  }

  float frequency = 1000000.0 / period;

  return frequency;
}

IrColor detectIrColor(float frequency) {
  if (frequency >= RED_MIN && frequency <= RED_MAX) {
    return IR_RED;
  } else if (frequency >= BLUE_MIN && frequency <= BLUE_MAX) {
    return IR_BLUE;
  } else {
    return IR_UNKNOWN;
  }
}

const char* irColorName(IrColor color) {
  switch (color) {
    case IR_RED:
      return "RED";

    case IR_BLUE:
      return "BLUE";

    default:
      return "UNKNOWN";
  }
}

CRGB irColorToLed(IrColor color) {
  switch (color) {
    case IR_RED:
      return CRGB::Red;

    case IR_BLUE:
      return CRGB::Blue;

    default:
      return CRGB::Black;
  }
}

void updateIrDisplay() {
  if (!ENABLE_IR_DISPLAY) {
    ir1.frequencyHz = 0.0;
    ir2.frequencyHz = 0.0;
    ir3.frequencyHz = 0.0;

    ir1.color = IR_UNKNOWN;
    ir2.color = IR_UNKNOWN;
    ir3.color = IR_UNKNOWN;

    return;
  }

  unsigned long now = millis();

  if (now - lastIrUpdateTime < IR_UPDATE_INTERVAL_MS) return;

  lastIrUpdateTime = now;

  ir1.frequencyHz = readFrequency(IR1_PIN);
  ir2.frequencyHz = readFrequency(IR2_PIN);
  ir3.frequencyHz = readFrequency(IR3_PIN);

  ir1.color = detectIrColor(ir1.frequencyHz);
  ir2.color = detectIrColor(ir2.frequencyHz);
  ir3.color = detectIrColor(ir3.frequencyHz);
}

void printOneIrSensor(const char* label, IrReading reading, int colorWidth) {
  Serial.print(label);
  Serial.print(": ");

  const char* colorText = irColorName(reading.color);
  Serial.print(colorText);

  int len = strlen(colorText);

  for (int i = len; i < colorWidth; i++) {
    Serial.print(" ");
  }

  Serial.print(" ");
  Serial.print(reading.frequencyHz, 1);
  Serial.print(" Hz");
}

void printIrData() {
  printOneIrSensor("IR1", ir1, 8);
  Serial.print(" | ");

  printOneIrSensor("IR2", ir2, 8);
  Serial.print(" | ");

  printOneIrSensor("IR3", ir3, 8);
  Serial.println();
}


// LED state update, this shows several procces during the operation
void updateLeds() {
  unsigned long now = millis();
  unsigned long elapsed = now - robotStartTime;

  bool timeFinished = elapsed >= TOTAL_RUN_TIME_MS;
  bool blink = ((now / 300) % 2) == 0;

  fill_solid(leds, NUM_LEDS, CRGB::Black);

  // LED1: selected team
  leds[LED1_TEAM] = teamLedColor(activeTeam);

  // LED2: general status
  if (timeFinished || navState == STATE_FINISHED) {
    leds[LED2_STATUS] = CRGB::Yellow;
  } else {
    leds[LED2_STATUS] = blink ? CRGB::Yellow : CRGB::Black;
  }

  // LED3:
  // BLUE=navigating
  // GREEN=reached deployment point
  if (navState == STATE_FORWARD_WALL_FOLLOW ||
      navState == STATE_LATERAL_SEARCH ||
      navState == STATE_APPROACH_DEPLOY) {

    leds[LED3_MOTION] = CRGB::Blue;

  } else if (navState == STATE_DEPLOY_WAIT) {

    leds[LED3_MOTION] = CRGB::Green;

  } else {

    leds[LED3_MOTION] = CRGB::Black;
  }

  leds[LED4_IR1] = irColorToLed(ir1.color);
  leds[LED5_IR2] = irColorToLed(ir2.color);
  leds[LED6_IR3] = irColorToLed(ir3.color);

  FastLED.show();
}
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
void loop() {
  updateAllWheelControllers();

  updateUltrasonicSensors();
  // This always reads the IR frequency and updates LED4, LED5, LED6.
  updateIrDisplay();
  updateNavigation();
  updateLeds();
  if (millis() - lastPrintTime >= PRINT_INTERVAL_MS) {
    lastPrintTime = millis();
    Serial.println();
    printTeamSelector();
    Serial.print("Time elapsed: ");
    Serial.print((millis() - robotStartTime) / 1000.0, 1);

    Serial.print(" s | State: ");
    Serial.print(stateName(navState));

    Serial.print(" | Movement: ");
    Serial.println(currentMovementName);

    printIrData();
    printSensorData();
    printWheelData();
  }
}

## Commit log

2026-05-03 initial schematic
    [LEDS.kicad_sch, distance.kicad_sch, lab7.kicad_pcb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]
2026-05-03 change arduino
